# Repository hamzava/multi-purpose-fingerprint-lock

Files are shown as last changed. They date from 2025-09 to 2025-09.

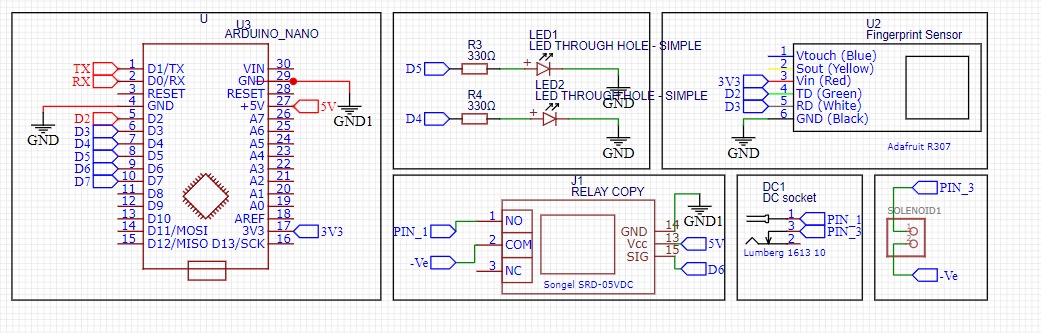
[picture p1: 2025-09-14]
Hardware/Circuit Schematic.jpeg

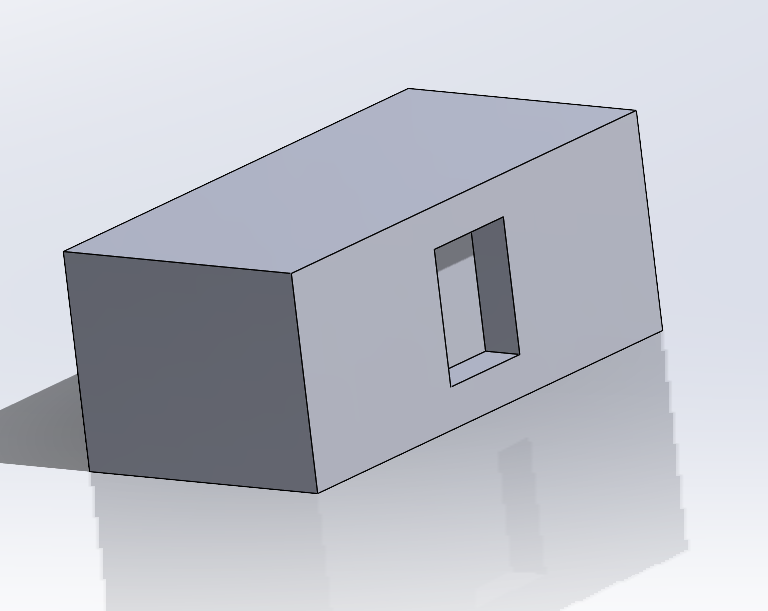
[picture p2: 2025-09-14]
Hardware/Case/image (2).png

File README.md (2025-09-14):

# Multi-Purpose Fingerprint Lock (Budget-Constrained Group Project)

Fingerprint Lock Prototype  

A prototype access-control system designed to provide **secure, low-cost, and user-friendly** locking solutions for doors, safes, and other objects requiring controlled access.  
This project was developed under strict **budget (£100)** and **time constraints**, highlighting practical engineering trade-offs and teamwork.

---

## 📖 Overview
Unauthorized access remains a persistent problem in both domestic and commercial settings.  
This project addresses the issue by designing a **fingerprint-based lock** using affordable components, while keeping the solution **multi-purpose and commercially feasible**.  

The prototype demonstrates how biometric authentication can be adapted into a cost-sensitive and scalable design.

---

## 🎯 Objectives
The project team set out to design a lock that is:
1. **Cheap** – affordable prototype made under £100.  
2. **Multi-purpose** – usable for doors, safes, and other lockable objects.  
3. **Commercially feasible** – potential to scale down costs via wholesale components.  
4. **Easy to use** – simple enrollment and unlocking process.  
5. **Secure** – reliable fingerprint authentication.  

---

## 🛠️ Development Process
1. **Hardware Integration** – Fingerprint sensor and solenoid wired to Arduino via a custom PCB.  
2. **Software Setup** – Libraries installed for fingerprint module and solenoid lock in Arduino IDE.  
3. **Programming** – Arduino coded to store fingerprints and trigger solenoid based on authorized access.  
4. **Testing & Debugging** – Prototype tested repeatedly to ensure consistency and security.  
5. **Enclosure Design** – Custom case built to house the PCB and lock mechanism, simulating a commercial product.  

---

## 📚 Research & Background
- **Theory**: Based on biometric authentication — unique physical characteristics (fingerprints) ensure reliable access control.  
- **Research**: Studied fingerprint recognition algorithms, available sensor types, and related security risks.  
- **Feasibility**: Compared with market products (~£90–£110 retail). Our prototype cost **£72.69 Total**, with scope for significant cost reduction in mass production (bulk components, no repeated R&D).  

---

## ⚙️ Hardware Components
- Arduino (ATmega-based)  
- Fingerprint Sensor Module  
- Solenoid Lock  
- Custom PCB  
- Power Supply  
- Enclosure (prototype casing)

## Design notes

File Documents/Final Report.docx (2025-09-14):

MULTI PURPOSE FINGERPRINT

LOCK

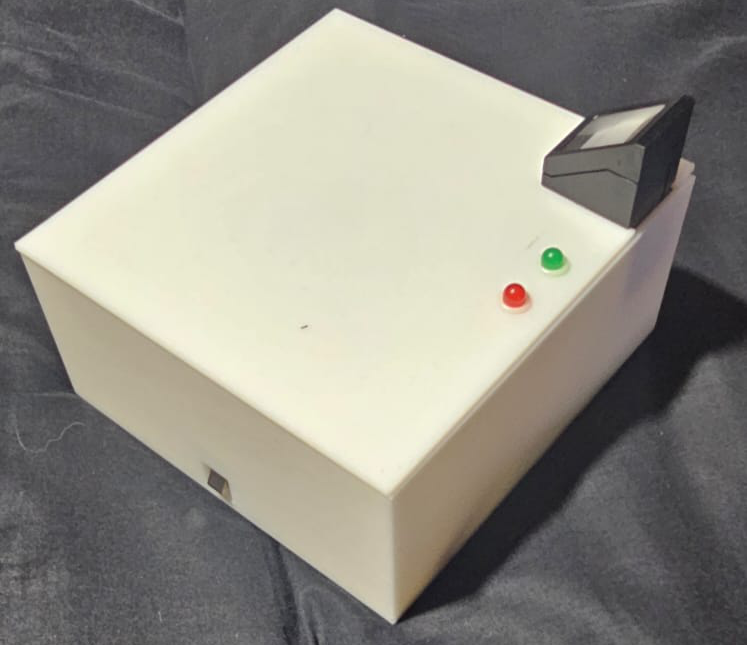
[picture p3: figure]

Group 1

Hamza Afzal, M.Ahsan Asif, Cameron Jones, Alex Ainsworth

# Introduction:

The purpose of this report is to document the development and evaluation of a multi-purpose fingerprint lock prototype, which was designed using an Arduino, fingerprint sensor, and a solenoid. The aim of the prototype is to provide a secure and convenient way to lock and unlock doors, safes, and other objects that require controlled access.

## Objectives/Problem:

The primary objective of the project was to design and develop a fingerprint lock that can be easily installed and configured to meet specific requirements. The project aimed to address the problem of unauthorized access to objects by providing a secure and reliable access control system.

Our goal was to design a fingerprint lock which is:

1. Cheap
2. Multi-purpose
3. Commercially feasible
4. Easy to use.
5. Secure

## Development:

The technique and procedure used for the development of the prototype involved the following steps:

1. Wiring the fingerprint sensor and solenoid to the Arduino board using PCB.
2. Installing the necessary libraries for the fingerprint sensor module and solenoid lock in the Arduino IDE software.
3. Programming the Arduino board to read fingerprints from the sensor and control the solenoid lock based on the authorized fingerprints.
4. Testing and debugging the prototype to ensure that it works as expected.
5. Creating a suitable case to hold the PCB and other components while making sure it is ready for commercial market.

# Background Research:

## Scope:

The scope of the project was to design and develop a prototype device that can be used for a variety of applications such as door locks, safe locks, and other objects that require controlled access. The prototype was designed to be easy to use, easy to install, and customizable to meet specific requirements.

## Theory:

The prototype was based on the theory of biometric authentication, which is a technology that uses unique physical or behavioural characteristics to verify the identity of an individual. The fingerprint sensor module used in the prototype is a type of biometric technology that scans and matches fingerprints to authorized users to provide secure access.

Research: Prior research on biometric authentication and fingerprint recognition was reviewed to determine the best practices for designing and developing a reliable and secure fingerprint lock prototype. The research focused on the different types of fingerprint sensors available, the algorithms used for fingerprint recognition, and the security risks associated with biometric authentication.

## Feasibility:

To justify the feasibility of the project, we will have to look at similar products. To do that we browsed Amazon and located products which are similar to ours and their application is similar to ours. Those products are available for sale, retail, ranging for 90-110 GBP. We made one single prototype under a budget of 100 GBP. If we are able to scale our product, we will have to buy components at wholesale rate which will reduce the cost. In addition to this, as R&D is not required for every product, that will also further reduce the cost.

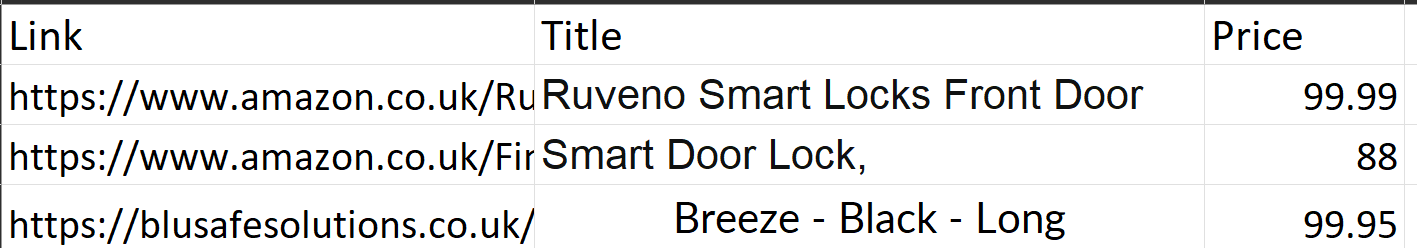
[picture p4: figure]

Price analysis

# Development & Test and Evaluation of Prototype:

Equipment, Apparatus and Technique & Procedure: The prototype was developed using the following equipment and apparatus:

1. Arduino Nano board

Worked as the core of the project. Holds the flash memory which include the code and fingerprints and co-ordinates between all the components because of the microprocessor it has.

2. Fingerprint sensor module

It is connected to the Arduino to scan the fingerprint and the Arduino processes it and stores it into it’s flash memory.

3. Solenoid lock

The solenoid lock is connect to the relay and Arduino. Relay acts as switch which receives the signal from Arduino. The signal determines that if the lock is supposed to be open or not. In either case Relay responds in such a way that solenoid behaves according to what we want.

4. USB cable

It was used to flash the code onto the Arduino.

5. Computer with Arduino IDE software

We wrote the code in Arduino IDE software so we could flash it later to the Arduino.

6. Solidworks
  a. Used to design the casing of the project and get it 3d printed.

# Design Phase

The casing was designed in Solidworks. Solidworks is a pretty good tool to design any 3d Object. Further it gives us option to save the file in such formats that we can get it 3d printed.

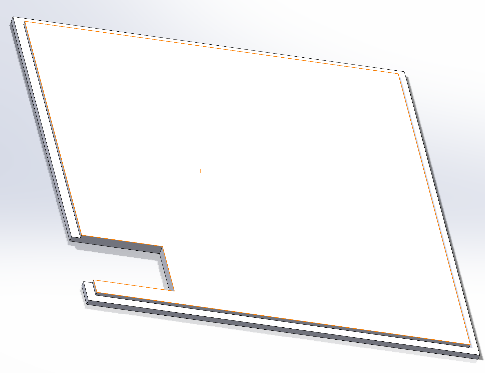
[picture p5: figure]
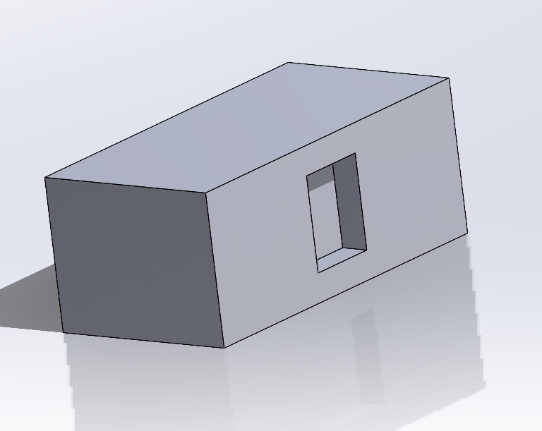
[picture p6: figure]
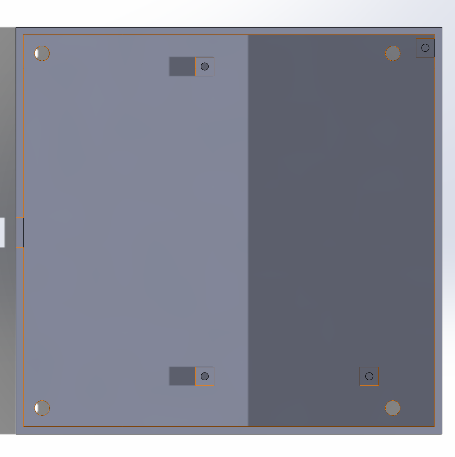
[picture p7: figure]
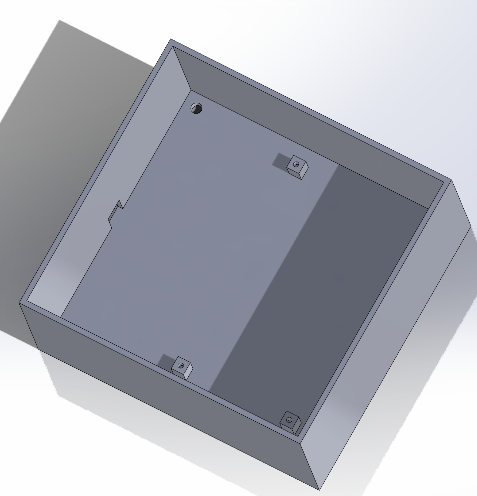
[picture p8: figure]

## Hardware:

Initially, we were able to demonstrate that our idea works. But the project was on breadboard. Usually that is the case with first prototypes, that they are on breadboard to show that it works because it is easier to change things as that is more of a test and improve approach.

We had ordered an external DC jack to power our project. So we would have different power source for solenoid as it draws 9V DC and a different power source for Arduino and other components. But we were able to figure out a way that we would only supply 9V to Arduino which in return would be able to power all the components.

Then when we had made sure that the project works, we changed the schematics. And we turned the schematics to a PCB. All our designing was done in EasyEDA. A technical part here was to make sure that the tracks which are going to be used for power are thicker than normal. Also we wanted to be on the safe side as well. The design of the PCB was as such that when we solder the components they are conveniently accessible. So placing the components at right place was really important. Furthermore, we had to design a lot of the components in EasyEDA as they weren’t available in the Library. Hence, this led to very accurate through holes in the PCB to solder components on.

When we tested the project, we were sure that we will only be using these parts. So we didn’t order any parts after that. This was also the plan because we discussed the components very thoroughly earlier in the R&D stage.

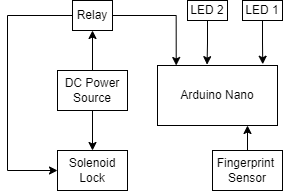
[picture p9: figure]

Hardware Block Diagram

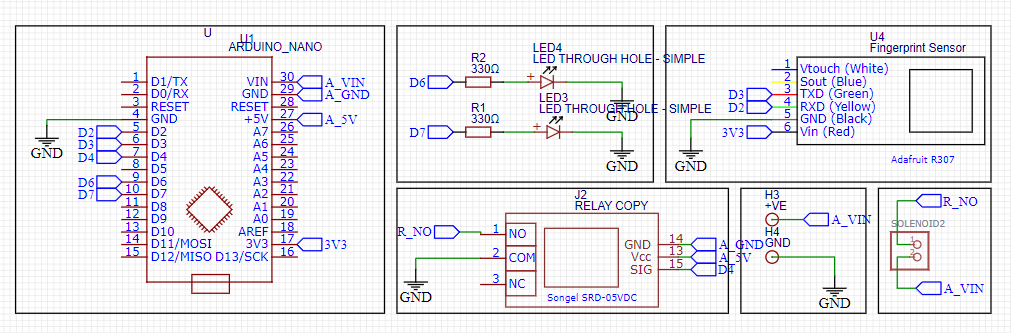
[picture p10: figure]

Circuit Schematic Diagram

After thinking about the hardware we discussed what are the appropriate components we needed for this project. So for that we did a lot of research as we had to make sure we are in our budget. After doing our research and finding appropriate components we ordered the following components.

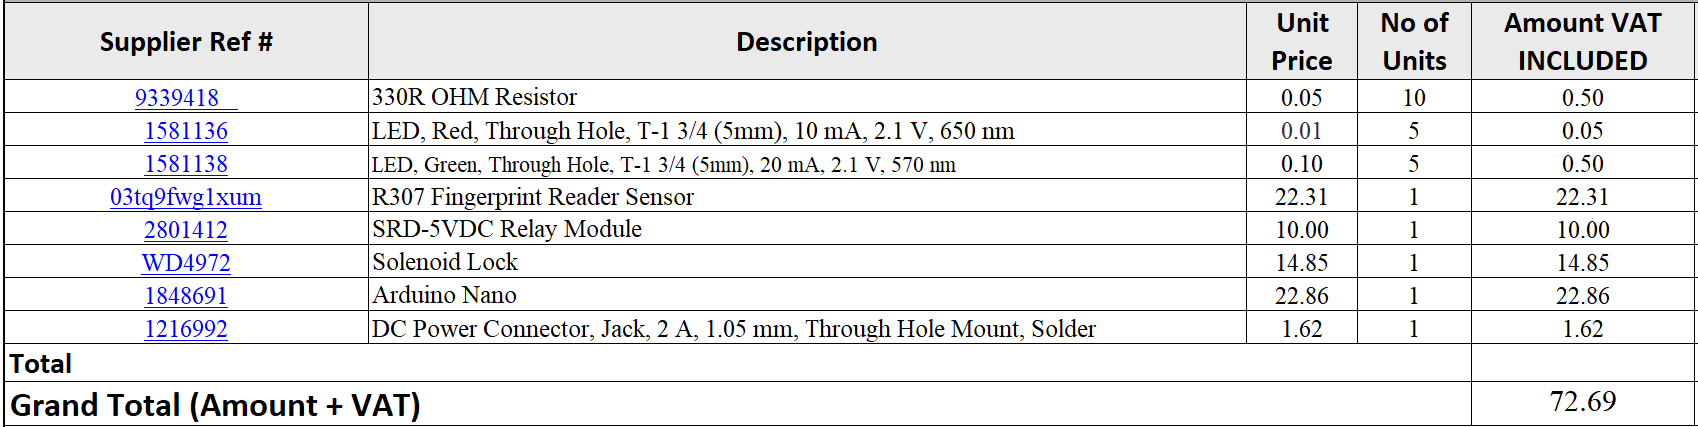
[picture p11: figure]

Order Form

## Software:

Our software’s algorithm is very straightforward. This helped us make the product work quicker. If we added more complexity, we were afraid that the response of the system might be slower. The current response time is about a second for registered fingerprints.

We have two parts of the code. First part is used to register the fingerprints. We can register up to 120 fingerprints. The code access’s the fingerprint module and it takes the picture of the fingerprint which is put onto it. The image is stored into the flash memory of the Arduino. This is the only part of the first code.

In the second code, the code access’s the fingerprint module. It takes the image of the fingerprint which on the module, it then compares that image with rest of the images stored in the memory. If the fingerprint is matched with any of the stored fingerprints. If it is the Arduino signals the Relay, which in return triggers the solenoid to an open state and changes the Led colour to Green. If the case is opposite, it does nothing, but keeps the Red Led on.

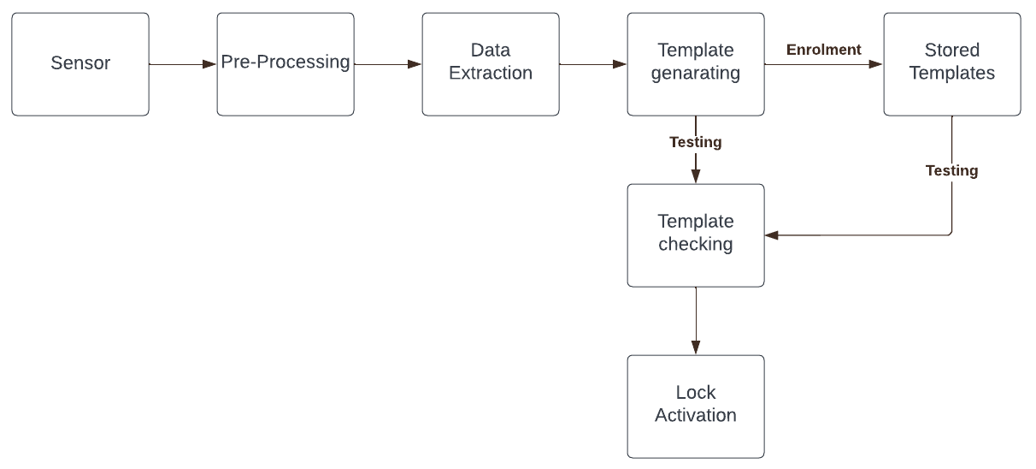
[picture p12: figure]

Combined Flowchart of the Software

# Testing:

The following procedure was used to test the prototype:

When the components came in, we got some faulty components as well. Which led us to check each component before we use that. For instance LED’s were supplied the required voltage individually through a power supply to make sure they are working and also making sure that they are not dim as we needed the perfect LED’s.

It is worth mentioning that we spent our budget not on 1 single quantity of each component, we ordered the parts in multiple quantities so that if anything goes wrong we are able to replace it except the Fingerprint sensor module and Arduino as they are expensive and for which we can get a work around. We got in multiple LED’s, Resistors and Solenoids according to the plan.

We used a multi meter which was provided by the university, to check voltage across the components and we made sure that they are only drawing enough current which is required to work. After that we made sure that all the components function properly. For instance, for fingerprint sensor we had to wait until the final code stage to check if it works. Although it did light up when the power was supplied but we still wanted to make sure that it read the fingerprint properly. Furthermore, we inspected the components visually, which came in help when the PCB’s arrived. There was a scratch on one of the PCB’s which would lead to a damaged track. So, we had to rule that PCB out and use another one as we had multiple PCB’s.

## Durability and Reliability Testing

For the durability testing of the product as we know most of the products were ordered and not made by ourselves, we were bound to follow the limitations set by the manufacturer. It is recommended that the product is used in an environment that has room temperature and moderately humid. But we worked out a range of from minus 5 degrees Celsius up to 45 degrees Celsius. This range also has been set up in such a way that the product will be safe to use in most of the case. This overall range has been worked out by considering the limits given to us by manufacturers. To prove that this range is perfectly fine we did put our product in the freezer for a - 5 degree test. And to test that it is fine to black in 45 degrees we used an oven. The test did go somewhat successful but at higher temperatures we know that usually the product do perform a little slower. But we think that if it is put into 45 degrees for a consistent amount of time the casing might get damaged. As the casing is 3D printed for prototyping purposes it might not cope with higher temperatures. The 3D printed cases depend on various factors. Like the amount of material we fill the object with. Hence that is what their prices and weight depends on. So we have to consider these factors when designing for commercial purposes.

(ada, n.d.) Fingerprint Module Temperature Rating

(Arduino, n.d.) Arduino Nano Temperature rating

(Farnell, n.d.) Solenoid Temperature Rating

Another important thing was the rejection rate and false acceptance rate of the fingerprint sensor.
Rejection rate is the rate with which the fingerprint sensor rejects a correct fingerprint. That usually is 1 in 100 if the fingerprint is maintained well like being keep free of dust and debris. This was verified by doing the experiment practically. And it was successful and upto the mark.

False acceptance rate is when fingerprint opens the lock with unauthorized fingerprint or it matches X’s fingerprint with Y’s. That ratio is 0.001 in 100 which is given by the manufacturer. As far as we used the fingerprint we never came across such a scenario while we had this in mind.

(ada, n.d.) Fingerprint Module FAR

In the URS we were specified that the battery time should be at least 12 hours. But currently we are managing to get around 4 hours. Currently, we use a 9v non rechargeable battery. We haven’t connect it directly to the PCB so if the user want’s they can attach a rechargeable one to the connector.

## Safety Testing

Our product is a product which uses electricity. Hence the only harm could be user being exposed to electricity and the hazards which are driven by electricity e.g fire. We designed the product so that all the wires are contained inside the case further more there are no wires outside the case. We also checked for any short circuits in the PCB so that there is not fire in case of a short circuit. We made sure that all the connections do have enough solder and they are soldered properly in addition to this we made sure none of the solder is colliding with other soldered wire. We also had to make sure that none of the tracks are burnt while soldering or they are not damaged as a result of manufacturing fault because of which could also cause sparks later on subsequently leading to a fire.

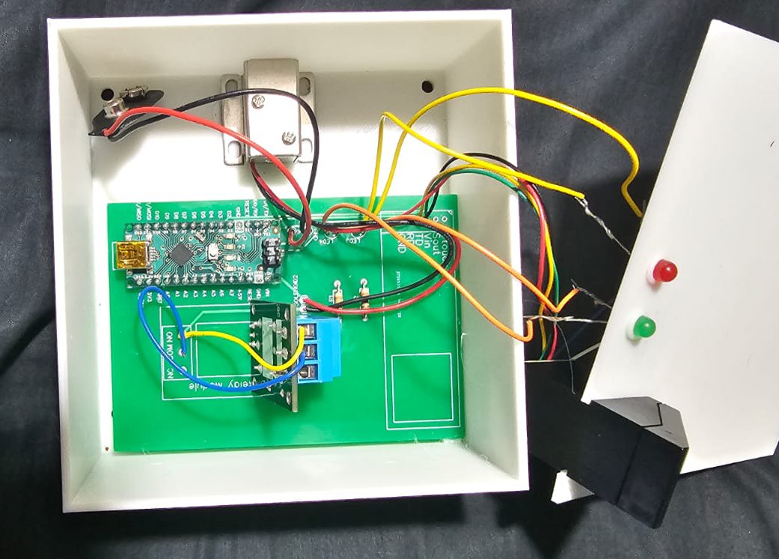
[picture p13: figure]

## User Testing.

Our product is designed completely from a consumer perspective. We were very conscious about the placement of components. Furthermore, we checked different position for fingerprint sensor, solenoid as well as LED to get the best possible position. This was a driving factor in the designing of the PCB as well as the 3D printed case. So the consumer of the product will be able to scan their fingerprint very easily as we have tucked the fingerprint module into the 3D case and made sure that it pops out. The reason that we wanted it to pop out was that the user should be able to scan their fingerprint properly. The current position of the fingerprint module made a 180 degree angle with the thumb or the finger of the user. And that was the best position determined after experimenting with the fingerprint module. In addition to this this was the position which gave us the best response from the system as we wanted the system to be quick enough to respond. If we scan the fingerprint in different position there was a high chance that the fingerprint won't be read properly.

Furthermore, the LED’s were put besides the fingerprint module because most of the times the user would be looking at the fingerprint sensor while scanning their finger or thumb. so while the user is looking at the fingerprint sensor when the fingerprint is scanned it would be shown on the green LED and it would give the user instant information that the lock is now open. So we had to also consider the psychology of the user. Another factor into designing our product was choosing the colour white. As we know that white colour absorbs less light hence it doesn't get heated that quickly. This was a drive from our side to make sure that we could be able to maintain the temperature of a running product as low as possible.

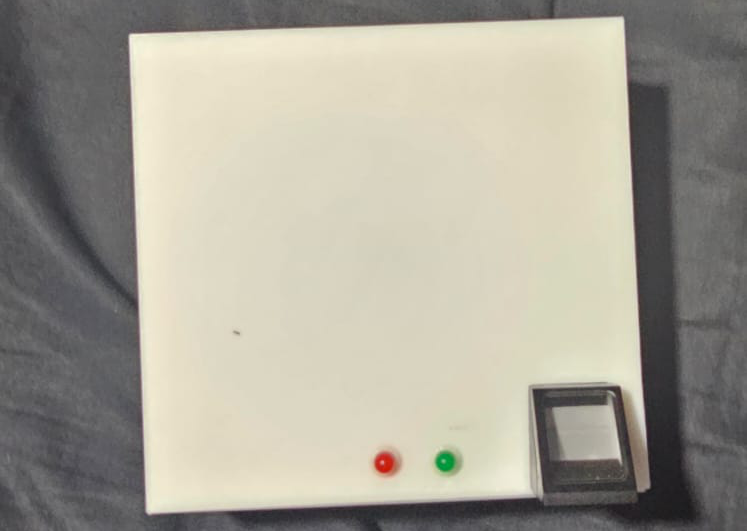
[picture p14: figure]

This testing was done by design and test approach because we wanted to initially design and think what we could improve over by testing the final model.

# Conclusion:

We were able to achieve the following outcomes from the project as in alignment with our interim report:

The prototype was successfully developed and tested, and the following results were obtained:

The fingerprint sensor module was able to accurately read and match fingerprints to authorized users.

The solenoid lock was able to lock and unlock object based on the authorized fingerprints.

The prototype was able to store multiple fingerprints and provide access to authorized users quickly and reliably.

Based on the results obtained, it can be concluded that the prototype is a reliable and secure way to control access to objects

## Reflection:

In our opinion our project could have been much better if the external factors didn’t matter as much.

First case is about the components. The deadline for to submit the order forms was before Christmas holidays which was met perfectly. But despite that we didn’t get our components on time as they were ordered after the Christmas holidays by the university. But we were able to produce a working prototype on a breadboard as it is much more feasible because of less Research and Development involved to develop a PCB. This was all done while meeting the deadline.

In another scenario for example, the PCB. We had guidelines to order the PCB through the university. But the PCB didn’t arrive until 2 days before we were supposed to present the final prototype. Although we had sent out the Gerber files just after we displayed our first prototype. Hence, we had very little time to implement the improvements we had thought about and ultimately the product was not somewhat we wanted. This all happened despite us meeting all our deadlines.

Furthermore we had lots of options which we could improve, for example one of the options was to decrease the on time for the red LED as it's usually on. We weren't able to do so because of the time constraints we had although this is a purely software based solution and this would also help us increase the battery time of the system. In addition to this one more change we wanted to do was that we wanted the system to be dependent on a lithium ion battery which are usually rechargeable. This would give the system the liberty of being remote which is specified in the URS but if we went for a DC Jack which means that the DC power is directly supplied from a outlet this would decrease the mobility of the system as they would need a socket to be beside or somewhere near the system.

If we were do add these things in the project I think the project would have been perfect considering the URS.

## Suggestion:

We met all our deadlines and completed the product we planned. But still in our opinion, it would have been much better that if we were authorized to order PCB’s and components. That would give us a much better grip on the project as we would be able to plan ahead of schedule.

# Manual:

1. Introduction

The multipurpose fingerprint sensor lock is a versatile security device that can be used to secure a wide range of items such as lockers, cabinets, and safes. It is equipped with advanced biometric technology that provides reliable and accurate identification of your fingerprints.

2. Installation

The installation process for the multipurpose fingerprint sensor lock will vary depending on the item you are securing. However, the basic steps are as follows:

Step 1: Prepare the item - Before installing the lock, ensure that the item is clean and free from any dust or debris. Remove any existing locks or hardware that may interfere with the installation.

Step 2: Install the lock - Align the lock with the hole on the item and insert the lock cylinder into the hole. Use the provided screws or adhesive tape to secure the lock in place.

Step 3: Install the battery - The lock is powered by 9V batteries. Open the compartment and insert the batteries according to the polarity markings.

Step 4: Register fingerprints - Follow the instructions provided to register your fingerprints. The lock can store up to 120 fingerprints.

3. Usage

Once the installation is complete and your fingerprints are registered, you can begin using the multipurpose fingerprint sensor lock. To unlock the item, simply place your finger on the sensor. The lock will quickly scan and verify your fingerprint before unlocking the item.

4. Maintenance

To ensure that the multipurpose fingerprint sensor lock continues to operate smoothly, it is important to perform regular maintenance. This includes:

- Keep the lock clean and free from dust and debris.
- Replace the batteries when they run out of power.
- Test the lock regularly to ensure that it is working correctly.
5. Troubleshooting

If you experience any issues with your multipurpose fingerprint sensor lock, please refer to the troubleshooting guide provided with the lock. Common issues include:

- The lock fails to recognize your fingerprint.
- The lock does not respond to input.
- The lock makes unusual sounds.

If you are unable to resolve the issue, please contact the manufacturer for assistance.

6. Conclusion

The multipurpose fingerprint sensor lock is a reliable and versatile security device that provides advanced protection for your valuable items. With proper installation, usage, and maintenance, you can enjoy many years of trouble-free operation.

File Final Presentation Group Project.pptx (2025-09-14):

## final GROUP PROJECT PRESENTATION

BY ahsan, hamza, alex and Cameroon

## introduction

- Introducing everyone's roles
- Why we chose a fingerprint lock?
- Improvements made to the model
- Conclusion

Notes: Demand in biometric authentication. AND ensuring security is met when using our fingerprint print lock

## Block diagrams

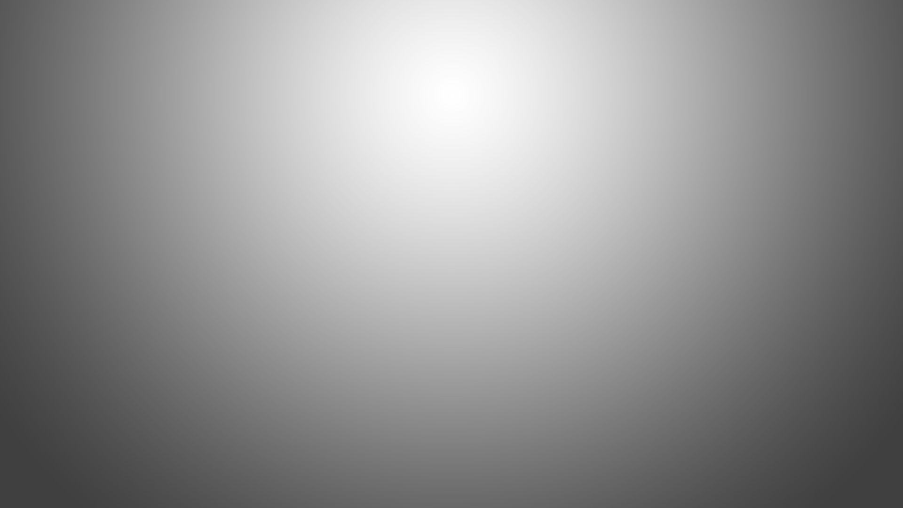
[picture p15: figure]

Hardware

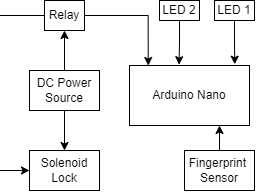
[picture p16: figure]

Software


## improvements

- CONVERTED BREADBOARD ONTO A PCB
- POWERED BY A 9V BATTERY
- CASE CREATED TO HOLD THE PROJECT
- COMMERICALLY SUITED

## Testing strategies

- Checked each component using a Multimeter
- Check voltage across each connection after soldering by using a Multimeter
- Used a power supply first then 9V battery

## CONCLUSION

- Gantt Chart targets met
- Completely working/assembled model
- Ready for launch

## Thank you for listening

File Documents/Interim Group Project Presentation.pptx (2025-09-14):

## Fingerprint lock with Arduino nano

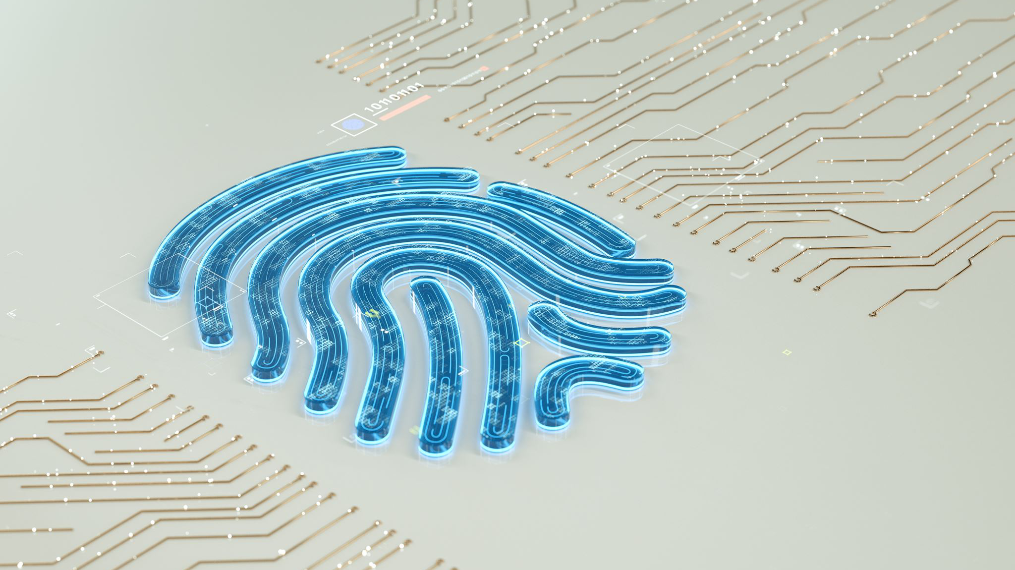
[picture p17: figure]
3D technology art

By Ahsan, Hamza, Alex and Cameron

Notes: Ahsan

Hello welcome all to our presentation. I’m Ahsan the group leader of this project and wanted to talk about our project which is about a Fingerprint lock with an Arduino Nano, In this presentation we will go over why we choose this project, the objectives and basic specifications of the product. The hardware and software details of the project and how we will test the project via the use of strategies. We will also include our Gantt Chart to show where we are in terms of the project and how much more we have left.

## Roles and Responsibilities

Ahsan : Group Leader : Overlooking group project and ensuring group sticks to tasks
Hamza : Secretary : Helps wherever possible and coordinating meetings
Alex : Hardware Engineer
Cameron : Software Engineer

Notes: First and foremost, I would like to introduce each of the members of the group and the responsibilities of each member, so everyone has an idea on what each member of the group is responsible for.

## Why a Fingerprint Lock?

## Basic System Objectives

1
The system must be able to store and manage multiple individual fingerprints.
2
The system must be able to accurately and reliably identify authorized individuals based on their fingerprints.
3
The system must be secure and resistant to tampering or unauthorized access.
4
The system must be able to grant or deny access to the secure area based on the verification results.

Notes: 2. So that there is no clash between the fingerprints

4. We two different coloured led for that.

## Basic Specification of the Fingerprint Scanner

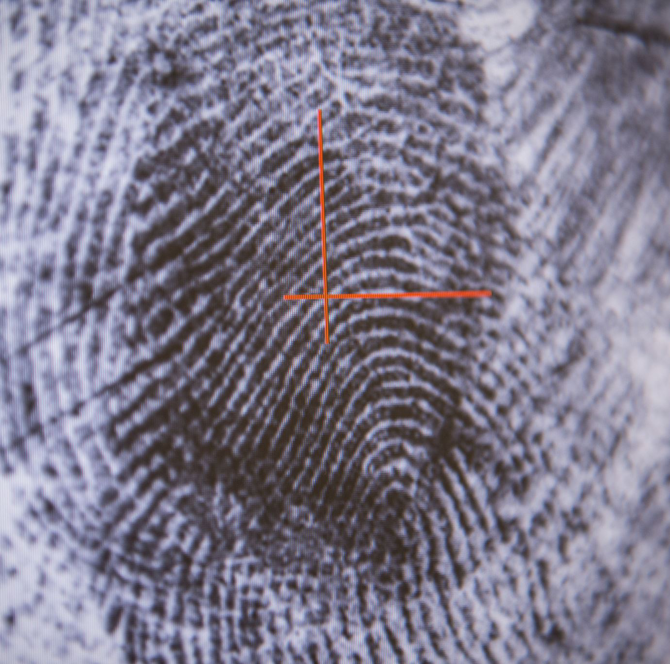
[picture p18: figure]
A fingerprint in black and white

- The system will use an optical fingerprint scanner.
- The system will use the flash memory microprocessor to store the fingerprint.
- The system will use the database of fingerprints in the flash memory to identify, and reject any false fingerprint.

## System Constraints & Assumptions

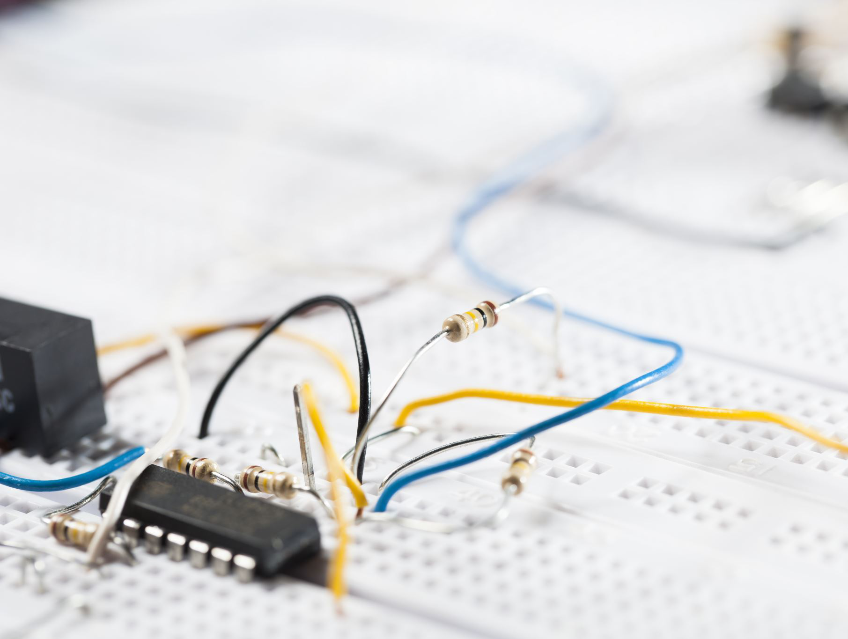
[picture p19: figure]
Electronics protoboard

- The system can be installed and used in a single location with a fixed secure area.
- The system will be connected to a power source.
- The system will be used by individuals with stable fingerprints.

## System Tolerances

- The system must have a high degree of accuracy, with a false acceptance rate (FAR) of no more than 0.001% and a false rejection rate (FRR) of no more than 1%.
- The system must be able to operate in a range of environmental conditions, including temperatures between -10°C and 50°C and relative humidity between 20% and 80%.
- The system must be able to operate continuously for at least 12 hours on a single battery charge.

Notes: alex

## Bill of Materials / Expenditure Description

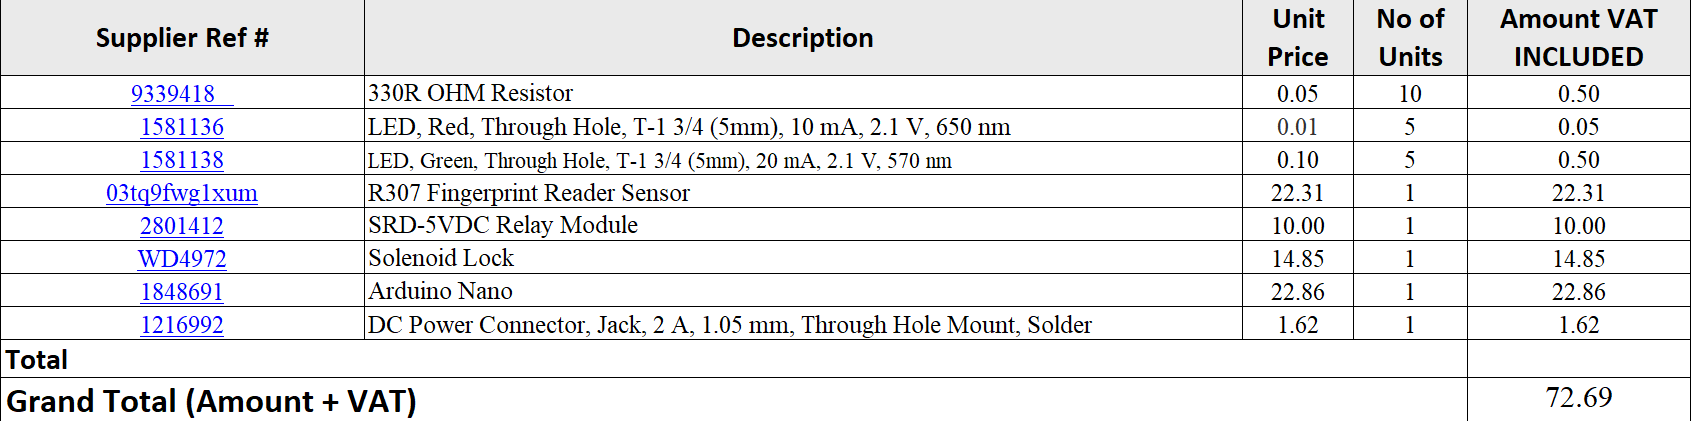
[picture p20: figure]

## Schematic Diagram & Block Diagram and : Hardware

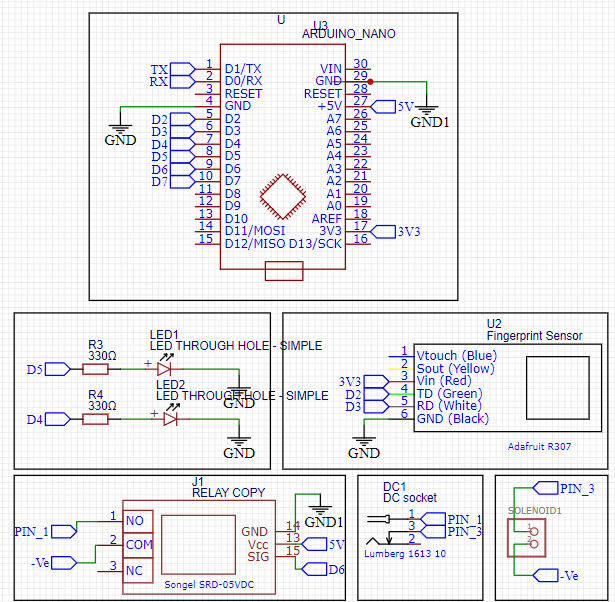
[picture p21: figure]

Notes: Hamza
Main Arduino
relay and solenoid connect to 12v dc because high powered Arduino supply’s 5v max


Fingerpritn sensor connected to Arduino signal to relay opens the solenoid

## Product Artifact and PCB

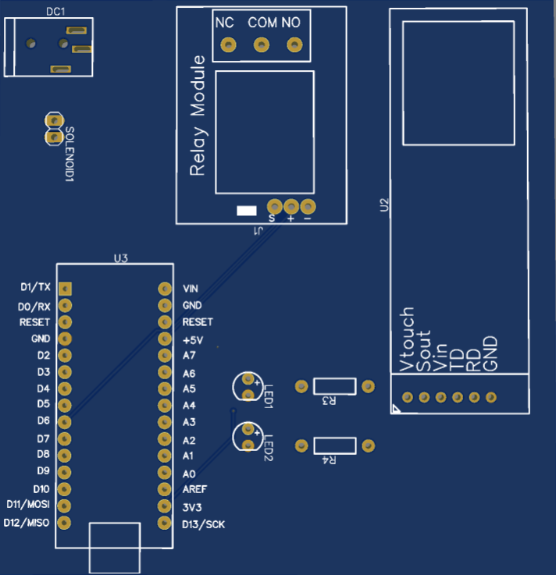
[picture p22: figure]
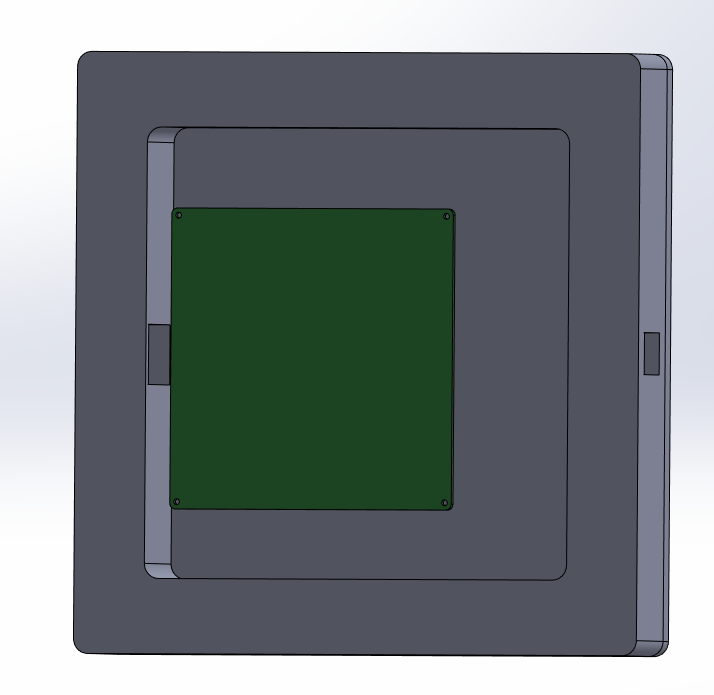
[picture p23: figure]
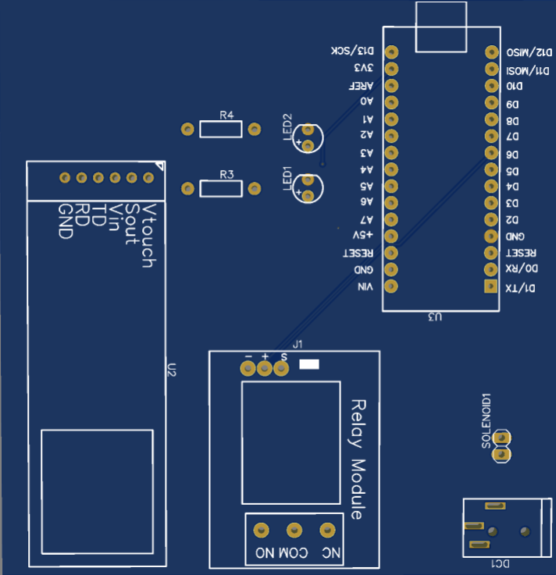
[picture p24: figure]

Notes: Hamza

## Testing Strategy

Functional Testing
Reliability Testing
Safety Testing
User Experience Testing

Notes: Hamza and Cameron

There are several testing strategies that you can use to test an electrical product, including the following:
Functional testing: This type of testing involves verifying that the product performs all of its intended functions correctly. This can include testing individual components, such as buttons, switches, and sensors, as well as testing the product as a whole to ensure that all of its functions work together properly.
Reliability testing: This type of testing is used to verify that the product is able to withstand the stresses of normal use and continue to function properly over time. This can include testing the product's durability, longevity, and resistance to damage or failure.
Safety testing: This type of testing is used to verify that the product is safe to use, both for the user and for any other individuals who may come into contact with it. This can include testing the product's electrical safety, such as ensuring that it complies with relevant safety standards and regulations.
User experience testing: This type of testing is used to evaluate how easy the product is to use and how well it meets the needs of the user. This can include testing the product's user interface, usability, and overall user experience.
These are just some examples of testing strategies that you can use to test an electrical product. The specific tests that you use will depend on the product and its intended use, and you may need to use a combination of different testing methods to thoroughly evaluate the product.

## Block Diagram and Specifications : Software


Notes: Cameron

## Risk Assessment

Risk No. | Description of the risk | Probability of the risk | Effect on the project | Contingencies/actions To mitigate the risk
1 | Burn from soldering iron. | If soldering iron is handled with care, probability of risk happening is low. | Can slow progress down as person will have to take care of injuries. | Wear heat proof gloves.
2 | Burn from hot solder splashing. | Fairly high probability of risk happening. | Takes up time but needing to take extra care is important for safety. | Wear long sleeves to protect skin and wear safety goggles to protect eyes.
3 | Short Circuit causing heat and possible fire. | High if components are damaged or not connected properly, very low if everything is connected as it should be. | Take extra time in building process as lots of attention will need to be put into the build to mitigate risk. | Test every component and connection/solder join, to make sure everything is in working order. This can be done easily by using a multimeter.
4. | Physical impact to fingers from building the product. | Fairly high if not being careful. Low if extra care is taken and you’re paying full attention to what you’re doing. | This will take extra time as it is most important to be safe when physically building the chassis of our product. | Keeping aware of surroundings and using building tools appropriately.
5. | Burn from welding | Heat and sparks could burn when welding, high probability without appropriate gear. | Will be strongest way of constructing our project but requires the correct knowledge on how to weld. | Wear correct protective gear and face shield, have the knowledge on welding techniques and methods.

## Gantt Chart

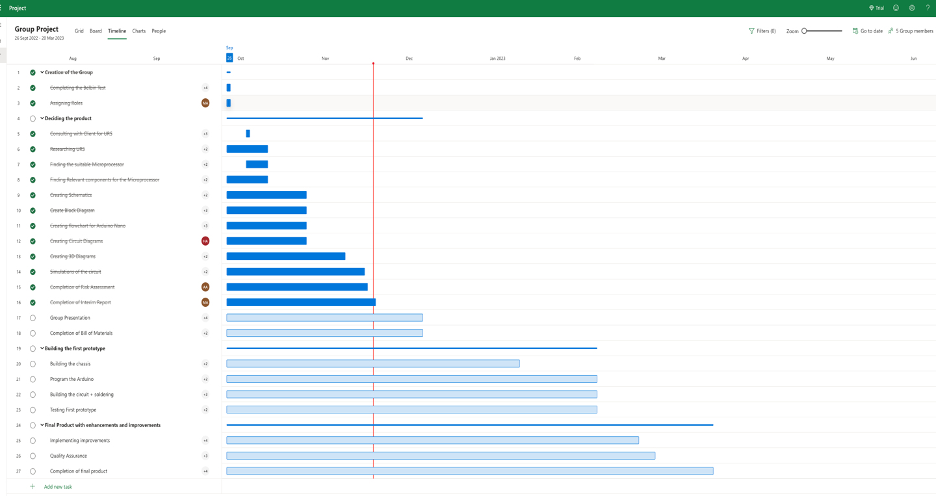
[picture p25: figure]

## Thank You for listening Any questions?

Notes: Ahsan

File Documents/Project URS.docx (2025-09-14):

#### 1. Introduction

This document describes the user requirements for a fingerprint lock system. The system will be used to control access to a secure area, allowing only authorized individuals to enter.

#### 2. General Requirements

- The system must be able to store and manage multiple individual fingerprints.
- The system must be able to accurately and reliably identify authorized individuals based on their fingerprints.
- The system must be easy to use and intuitive for authorized individuals to operate.
- The system must be secure and resistant to tampering or unauthorized access.

#### 3. Functional Requirements

- The system must be able to enroll new fingerprints and associate them with specific individuals.
- The system must be able to verify the identity of an individual based on their fingerprint.
- The system must be able to grant or deny access to the secure area based on the verification results.
- The system must be able to provide feedback to the user, such as indicating a successful verification or denying access.

#### 4. Non-Functional Requirements

- The system must have a high degree of accuracy, with a false acceptance rate (FAR) of no more than 0.001% and a false rejection rate (FRR) of no more than 1%.
- The system must be able to operate in a range of environmental conditions, including temperatures between -10°C and 40°C and relative humidity between 20% and 80%.
- The system must be able to operate continuously for at least 12 hours on a single battery charge.

#### 5. Constraints and Assumptions

- The system will be installed and used in a single location with a fixed secure area.
- The system will be connected to a power source.
- The system will be used by individuals with stable fingerprints.

6. User Interfaces

- The system will have a user interface consisting of a fingerprint scanner.
- The user interface will allow authorized individuals to enroll their fingerprints and access the secure area.
- The user interface will provide feedback to the user through LED’s, displaying a message indicating a successful verification or access denied.

#### 7. Technical Requirements

- The system will use a secure database to store enrolled fingerprints and associated information.

#### 8. Support and Maintenance

- The system will include a warranty period of at least 12 months.
- The system will be supported by the manufacturer with regular software updates and technical assistance.
- The system will be designed for easy maintenance and replacement of components, such as the fingerprint scanner or battery.

All rights reserved. Disclosure to third parties of this document or any part thereof, or the use of any information contained therein for purposes other than provided for by this document, is not permitted, except with prior and express written permission of Mobilefish.com. PROJECT-COMPANY-URD-00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

Multi Purpose Fingerprint Lock URS

Mobilefish.com document SDP-MF-URD-0001 javastreet 10 version 1.0 Zaandam date 3 Jul 2006 The Netherlands page i

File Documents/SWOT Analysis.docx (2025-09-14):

Strengths:

1. Accurate and reliable identification based on fingerprints
2. Secure and resistant to tampering
3. High degree of accuracy with low false acceptance and rejection rates
4. User-friendly and intuitive
5. Easy maintenance and component replacement

Weaknesses:

1. Limited to single location with fixed secure area
2. Dependent on power source
3. Limited to individuals with stable fingerprints

Opportunities:

1. Growing demand for secure access control systems
2. Potential for expanding to multiple locations
3. Integration with other security systems for enhanced security

Threats:

1. Competition from other security systems
2. Advancements in biometric technology may render fingerprint technology obsolete
3. Concerns about privacy and security of stored fingerprints.

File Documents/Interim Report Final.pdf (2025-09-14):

## Fingerprint Lock with Arduino Nano

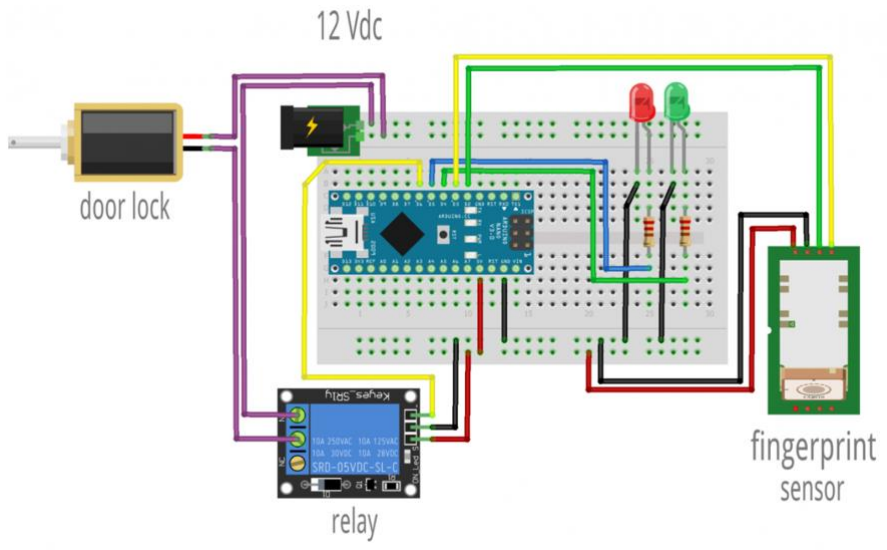
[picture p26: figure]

Authors: Muhammed Ahsan Asif, Hamza Afzal, Alexander Ainsworth and Cameron Jones

Supervisor: Ben Mehenni

Course: BEng Electrical and Electronic Engineering

Venue: University of South Wales Treforest Campus 2022-23

## Introduction

Our group project is to design and physically produce a robust fingerprint recognition lock with LED indicators that can be used to lock a safe. There are possibilities that our lock could extend into other prototypes and uses such as doors, suitcases, gates, cars, properties etc.

This project is being undertaken as fingerprint technology is now in widespread practice, which means we should learn about how the technology functions and try to understand how to build a product that can put it into practice. This project requires some coding as we are planning to use an Arduino Nano as our prototyping platform which contains an ATmega 328 microcontroller. The Arduino is to be powered via Micro USB. During the design of our project, we will learn how to code our lock so that it performs the specific tasks our product is required to do. This will also give an opportunity for our group to expand our understanding of how coding for the microcontroller works.

We plan to use a solenoid device as the foundation of our lock, specifically looking at the MP001162 Multicomp Pro, SOLENOID LOCK as our starting point. It is a small 12V, 9W solenoid and as we hopefully create more prototypes (for different purposes) we may change the solenoid as various products will require different specifications for the appropriate solenoid. The design will use LEDs to represent and indicate different states that the lock is in. Another option would be to use a small LCD screen, but this is impractical for a few reasons. LEDs will be cheaper, much more compact and space saving, more robust, much easier to code than an LCD screen and consume less power.

We will need to use a fingerprint sensor to receive information from somebody's fingerprint then transmit the information to the microcontroller. As we will have stored the fingerprint of the user, which is stored in the flash memory of the microcontroller, the microcontroller checks if the scanned fingerprint matches the fingerprint in the flash memory.

The fingerprint is going to be hardcoded in as this is the most secure way, we can do it due to weak security from the Arduino. However, we may use a different platform for subsequent prototypes such as Raspberry PI Pico which is more secure.

As we start to construct our project, we will need to make sure the dimensions of our project all fit together and are all compatible. It should fit in a safe chassis however if not our backup plan is to reengineer our locking system into a portable fingerprint lock or adapt it to different items such as a door, suitcase/briefcase lock.

Another point to add is we will need to solder our components onto a PCB containing the Arduino. We need to take care not to bridge any tracks, spill solder or break any components and therefore will require a steady hand.

## Summary/Background research of product

This section will talk about the background research which we have conducted for our idea and the justification of our chosen idea. Also, we will talk about the initial objections of our idea and how we dealt with these objections before finalising our idea.

Firstly, when deciding on our project, we thought of using the Renesas boards given to us in embedded for our project. This would be a viable option but due to our lack of knowledge of the architecture of the board and our programming skills for the board not being up to par, we decided not to use the Renesas board and decided on an Arduino Nano. An Arduino Nano was a viable option for us to use as it was inexpensive and most importantly easy to use. We could adapt pre-existing code which would help towards our project instead of completing learning how to program an embedded system which is hard for us to understand as of now or understanding an embedded systems architecture which we are unfamiliar with so we decided on an Arduino as we could implements more aspects into the Arduino as material is more available for it.

Now after deciding on using an Arduino Nano on our project, we needed to decide what we wanted to do with the Arduino. After brainstorming ideas, we decided on creating a safe lock with a fingerprint sensor. For us to work on this project, we needed to look at other lock systems with a fingerprint sensor to grasp the basics of how to conduct out project for our situation. This website demonstrates the use of a fingerprint scanner on a door lock system.¹ We can use the configurations of the fingerprint sensor from this project and use it in our project. After this discovery, we had the thought of using an RFID reader in our project. This website demonstrates the use of an RFID in an electric door lock.² The reason we didn’t decide to go forward with using an RFID due to the requirements of the user and to make the product as compact as possible. If we added the RFID, the size of the product which increase by at least 2 inches in dimensions.

Now, we have decided on the parts and have grasped the basic concepts of our project, now it’s time to find and research the schematics and circuit diagrams for our project.

1 Arduino Project Hub. (n.d.). DiY Fingerprint Door Lock System. [online] Available at:

https://create.arduino.cc/projecthub/diyprojectslab/diy-fingerprint-door-lock-system-98dcea.

2 Electric Door Lock With Fingerprint Scanner and RFID Reader. [online]. Available at:

https://www.instructables.com/Electric-Door-Lock-With-Fingerprint-Scanner-and-RF/. (https://create.arduino.cc/projecthub/diyprojectslab/diy-fingerprint-door-lock-system-98dcea)


3

Figure 1.1: Pin-out diagram of Arduino Nano

This image shows the pin-out diagram of the Arduino Nano takes from the Arduino website. This will allow us to understand how the Arduino works and tells us the significant of each pin and it’s use which will be useful for us.


4

Figure 1.2: Schematic of the Arduino Nano

3 Arduino® Nano. (n.d.). [online] Available at:

https://docs.arduino.cc/static/e7d6ca34b88350545d67282788df0956/A000005-datasheet.pdf

4 Figure 1.2, 1.3 and 1.4 : Arduino, n.d. Arduino Datasheet. [Online]
Avaliable at https://www.arduino.cc/en/uploads/Main/Arduino_Nano-Rev3.2-SCH.pdf


Figure 1.3: Schematic of the Microprocessor

Figure 1.4: Schematic of the USB Input

This is the schematic diagrams of the Arduino Nano, the microprocessor and the USB input taken from the Arduino website which is crucial for us as it allows us to render a 3d model of the Arduino Nano which can be rendered in Proteus.


5

Figure 1.5: Dimensions of the solenoid lock

6

Figure 1.6: Dimensions of the fingerprint sensor

5
Solenoid Lock Diagram Specifications Electrical Specifications. (n.d.). [online] Available at:

https://www.farnell.com/datasheets/2865763.pdf

6 Manual, U. (2011). R307 Fingerprint Module. [online] p.1. Available at:

https://www.openhacks.com/uploadsproductos/r307_fingerprint_module_user_manual.pdf

These are the dimensions of the solenoid lock and fingerprint sensor taken from the Farnell website. This diagram will allow us to redesign the solenoid lock and fingerprint scanner into proteus with the correct measurements and to create the 3D model of these two parts with precision.


6

Figure 1.7: Circuit diagram of Fingerprint sensor

This is the circuit diagram of fingerprint sensor taken from a GROW industries pdf which will allow us to understand the circuitry of the fingerprint sensor and the alignment of the pins which will be useful to us when constructing of the product.

6 Manual, U. (2011). R307 Fingerprint Module. [online] p.1. Available at: https://www.openhacks.com/uploadsproductos/r307_fingerprint_module_user_manual.pdf


7

Figure 1.8: Diagram of fingerprint scanner

This is a diagram which depicts how the fingerprint scanner works taken from the CircuitState website. This allows us to see what each of the scanner is and the purpose of each part of the scanner.

6

Figure 1.9: Schematic of fingerprint scanner

7
circuitstate.com. (n.d.). Interfacing R307 Optical Fingerprint Scanner with Arduino Boards for Biometric

Authentication - CIRCUITSTATE Electronics. [online] Available at: https://circuitstate.com/tutorials/interfacing-r307-

optical-fingerprint-scanner-with-arduino-boards-for-biometric-authentication/
6 Manual, U. (2011). R307 Fingerprint Module. [online] p.1. Available at: https://www.openhacks.com/uploadsproductos/r307_fingerprint_module_user_manual.pdf

This is the schematic of the fingerprint scanner taken from the GROW industries pdf. This will allow us to design of the fingerprint scanner in Proteus by helping us see where to wire each part with no complications. The schematic also allows us the render a 3D model of the sensor on Proteus so we can see a 3D model of the fingerprint scanner on Proteus.


Figure 2.10: Circuit Diagram of the planned product

This is a circuit diagram of our planned circuit which we design with a use of a breadboard. In our final project, instead of a breadboard, we will use a copper board and solder each of the components onto the board. This design gave us an insight on how the circuity would look like before constructing it in real life.

## Risk Assessment

- Generic risks

Generic Risks are risks that are generally there every day. Things like your surroundings and the scenario that you are in. For example, theft of materials, acts of God etc.

- Specific risks

Specific risks are risks that are special to the project of subject. This included things like making sure specific soldering techniques are being carried out. Soldering irons don’t generally have a place in everyday, urban environment.

Risk
No.

Description of
the risk

Probability of
the risk

Effect on the
project

Contingencies/actions
To mitigate the risk

### 1 Burn from

soldering iron.

If soldering iron is
handled with
care, probability
of risk happening
is low.

Can slow
progress down
as person will
have to take care
of injuries.

Wear heat proof gloves.

### 2 Burn from hot

solder splashing.

Fairly high
probability of risk
happening.

Takes up time
but needing to
take extra care is

Wear long sleeves to
protect skin and wear
safety goggles to
protect eyes.

| | | important for safety.
3 Short Circuit | causing heat and possible fire. | High if components are damaged or not connected properly, very low if everything is connected as it should be. | Take extra time in building process as lots of attention will need to be put into the build to mitigate risk. | Test every component and connection/solder join, to make sure everything is in working order. This can be done easily by using a multimeter.
4. Physical impact | to fingers from building the product. | Fairly high if not being careful. Low if extra care is taken and you’re paying full attention to what you’re doing. | This will take extra time as it is most important to be safe when physically building the chassis of our product. | Keeping aware of surroundings and using building tools appropriately.
5. Burn from | welding | Heat and sparks could burn when welding, high probability without appropriate gear. | Will be strongest way of constructing our project but requires the correct knowledge on how to weld. | Wear correct protective gear and face shield, have the knowledge on welding techniques and methods.

## WBS and Gantt Chart



These are the WBS of the tasks for the Gantt chart which was created on MS Project. Each task has a date and duration and has each of the members aligned to each task.


This is the Gantt chart of the overall project. The dark blue bars represent the completion of the tasks, and the light blue tasks shows the non-completion of tasks. The thin lines represent the duration of the overall task.

## Current state of project

As of the 18/11/2022, we have completed the Belbin test, assign roles, and have decided the project, completed the URS and have now completed the steps required for the Interim Report template. After submission, we will continue to update and use MS Project for tracking and start our next task which is preparation for the group presentation.

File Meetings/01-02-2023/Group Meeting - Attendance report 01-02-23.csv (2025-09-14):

1. Summary
Meeting title	Group Meeting
Attended participants	4
Start time	01/02/23, 22:50:48
End time	01/02/23, 23:12:59
Meeting duration	22m 11s
Average attendance time	21m 9s
2. Participants
Name	First join	Last leave	In-meeting duration	Email	Participant ID (UPN)	Role
Afzal H (FCES)	01/02/23, 22:50:52	01/02/23, 23:12:55	22m 2s	30052265@students.southwales.ac.uk	30052265@students.southwales.ac.uk	Organizer
Jones C (FCES)	01/02/23, 22:51:24	01/02/23, 23:12:59	21m 34s	30035734@students.southwales.ac.uk	30035734@students.southwales.ac.uk	Presenter
Ainsworth A (FCES)	01/02/23, 22:51:36	01/02/23, 23:12:56	21m 20s	30036209@students.southwales.ac.uk	30036209@students.southwales.ac.uk	Presenter
Asif M A (FCES)	01/02/23, 22:52:36	01/02/23, 23:12:16	19m 40s	30017471@students.southwales.ac.uk	30017471@students.southwales.ac.uk	Presenter
3. In-Meeting activities
Name	Join time	Leave time	Duration	Email	Role
Afzal H (FCES)	01/02/23, 22:50:52	01/02/23, 23:12:55	22m 2s	30052265@students.southwales.ac.uk	Organizer
Jones C (FCES)	01/02/23, 22:51:24	01/02/23, 23:12:59	21m 34s	30035734@students.southwales.ac.uk	Presenter
Ainsworth A (FCES)	01/02/23, 22:51:36	01/02/23, 23:12:56	21m 20s	30036209@students.southwales.ac.uk	Presenter
Asif M A (FCES)	01/02/23, 22:52:36	01/02/23, 23:12:16	19m 40s	30017471@students.southwales.ac.uk	Presenter

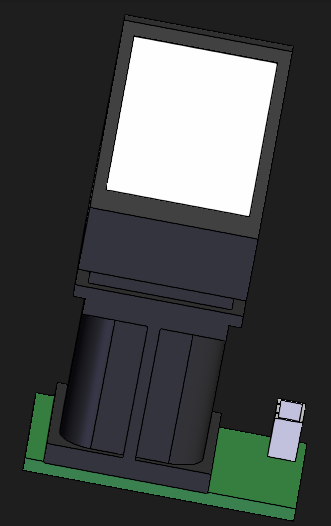
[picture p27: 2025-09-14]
Hardware/fingeprint.PNG

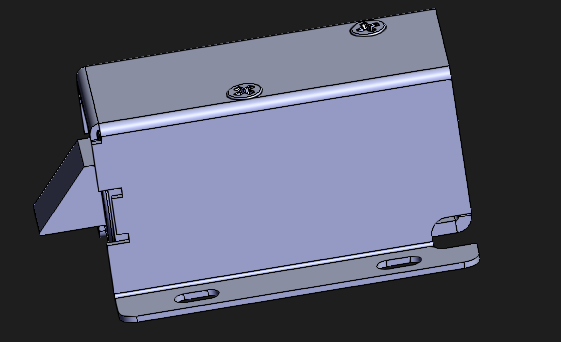
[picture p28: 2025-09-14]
Hardware/lock.PNG

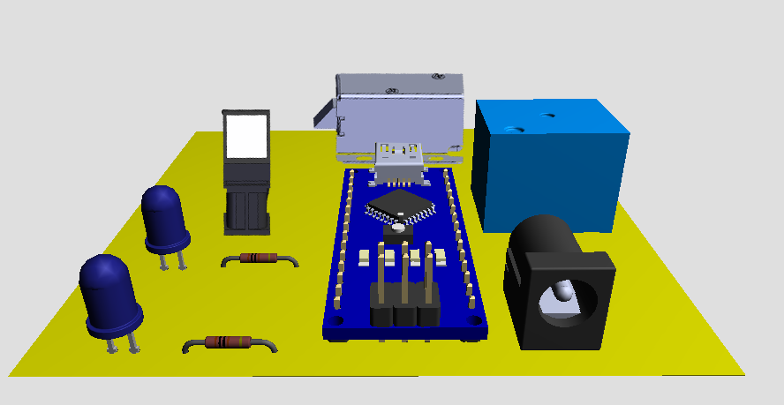
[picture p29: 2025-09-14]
Hardware/3d_Model.png

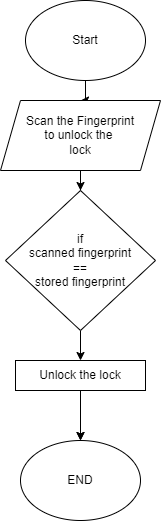
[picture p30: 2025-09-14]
Software/Flowchart 1.png

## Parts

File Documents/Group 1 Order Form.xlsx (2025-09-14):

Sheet: Sheet1
 |  |  |  |  | DFA ONLY
UNIVERSITY OF SOUTH WALES |  |  |  |  | Purchase method
FACULTY OF COMPUTING, ENGINEERING & SCIENCE |  |  |  |  | Date order raised
Please complete all the red mandatory fields, incomplete orders will not be processed. |  |  |  |  | Order Number
 |  |  |  |  | Nominal
EXPENDITURE REQUEST FORM
Section A
Date |  |  | Supplier Name and Address
Requested By
Credit Card / Order Request?
Budget Code
Department/Office
Authorisation (Print Name) Budget holder
 |  |  | Postcode:
Authorisation (Signature) |  |  | Tel No:
 |  |  | Fax No:
Goods or Services |  |  | If Equipment, please enter room where it is to be located :
Type of Goods / Services e.g. Software / Hardware |  |  | J407
Section B - Expenditure Description
Supplier Ref # | Description |  |  | Unit Price | No of Units | Amount VAT INCLUDED
9339418 (https://uk.farnell.com/multicomp/mcf-0-25w-330r/res-330r-5-250mw-axial-carbon/dp/9339418) | 330R OHM Resistor |  |  | 0.05 | 10 | 0.50
1581136 (https://uk.farnell.com/multicomp-pro/mcl053pd/led-5mm-36-hi-red/dp/1581136?MER=TARG-MER-PDP-RECO-STM7193) | LED, Red, Through Hole, T-1 3/4 (5mm), 10 mA, 2.1 V, 650 nm |  |  | 0.01 | 5 | 0.05
1581138 (https://uk.farnell.com/multicomp/mcl053gd/led-5mm-36-green/dp/1581138?st=green%20led%20through%20hole%205mm) | LED, Green, Through Hole, T-1 3/4 (5mm), 20 mA, 2.1 V, 570 nm |  |  | 0.10 | 5 | 0.50
03tq9fwg1xum (https://www.amazon.co.uk/Optical-Fingerprint-Attendance-Deposit-Control/dp/B08J48XZX4?hvadid=501068133807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) | R307 Fingerprint Reader Sensor |  |  | 22.31 | 1 | 22.31
2801412 (https://uk.farnell.com/mcm/83-17990/5v-trigger-relay-module-for-arduinoraspberry/dp/2801412) | SRD-5VDC Relay Module |  |  | 10.00 | 1 | 10.00
WD4972 (https://www.amazon.co.uk/QWORK-Electric-Solenoid-Assembly-Electirc/dp/B093H6GD4V?hvadid=570437819890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) | Solenoid Lock |  |  | 14.85 | 1 | 14.85
1848691 (https://uk.farnell.com/arduino/a000005/arduino-nano-evaluation-board/dp/1848691) | Arduino Nano |  |  | 22.86 | 1 | 22.86
1216992 (https://uk.farnell.com/lumberg/1613-10/socket-low-voltage-1-05mm/dp/1216992?st=lumberg+1613+10) | DC Power Connector, Jack, 2 A, 1.05 mm, Through Hole Mount, Solder |  |  | 1.62 | 1 | 1.62
Total
Grand Total (Amount + VAT) |  |  |  |  |  | 72.69
Section C Vehicle Hire PLEASE REFUEL VEHICLE
Delivery Date & Time
Delivery Point
Collection Date & Time
Collection Point
Vehicle Type / Description
Name(s) of Driver(s)
Purpose of Hire
Other Details : D.O.B |  | Flight no. : | Contact No. |  |  | Other Info
Driving Licence No. |  | Start date: | End Date
Failure to Refuel Vehicle will result in additional Charges and possible removal of service
Section D Accommodation Requirements ( only to be completed if not included in Uniglobe / Portman quote)
Name of Hotel
Address of Hotel
Hotel Telephone No / Fax No.
Dates Required
Number of Rooms Required
Names of Personnel
Additional Info Web address / Ref
Please submit electronically via email to: AT Expenditure Requests (AT)

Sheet: Sheet2
Credit Card | Goods | Electronic
Purchase Order | Services | Email attached

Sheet: Sheet3
Component | Arduino Nano Pin | Connection
Fingerprint RX | 2 | RX on fingerprint sensor
Fingerprint TX | 3 | TX on fingerprint sensor
Password | Not a pin
Relay COM | 5V | 5V on Arduino Nano
Relay NO | Solenoid + | Positive terminal on solenoid
Relay IN | 4 | IN on relay
Solenoid - | GND | GND on Arduino Nano
LED1 anode (+) | 6 | 6 on Arduino Nano
LED1 cathode (-) | GND | GND on Arduino Nano
LED2 anode (+) | 7 | 7 on Arduino Nano
LED2 cathode (-) | GND | GND on Arduino Nano
Fingerprint GND | GND | GND on Arduino Nano
Relay GND | GND | GND on Arduino Nano
Solenoid GND | GND | GND on Arduino Nano
Fingerprint VCC | 5V | 5V on Arduino Nano

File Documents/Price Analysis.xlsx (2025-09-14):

Link | Title | Price
https://www.amazon.co.uk/Ruveno-Fingerprint-Keyless-Electronic-Biometric/dp/B0B9XQJ3NP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 | Ruveno Smart Locks Front Door | 99.99
https://www.amazon.co.uk/Fingerprint-Bluetooth-Control-Perfect-Apartment/dp/B09P4W8SRY | Smart Door Lock, | 88
https://blusafesolutions.co.uk/product/breeze-black-long/ | Breeze - Black - Long | 99.95

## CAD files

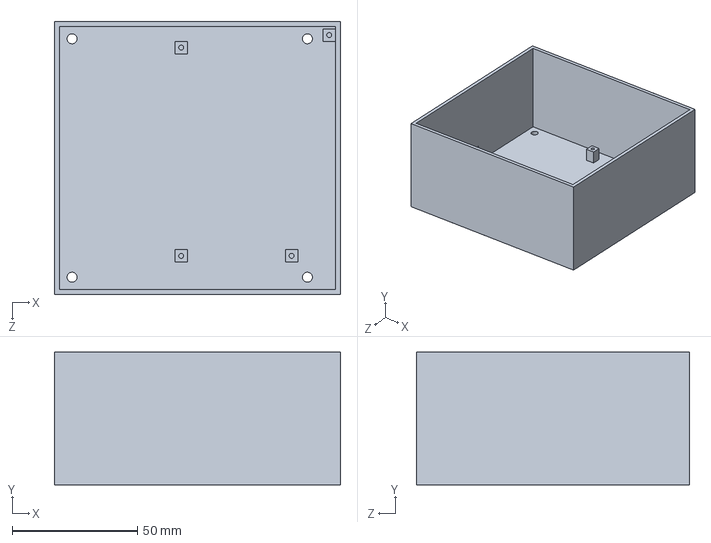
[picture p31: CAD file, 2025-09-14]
Hardware/Solidworks/box.SLDPRT
114.0 x 53.0 x 109.0 mm

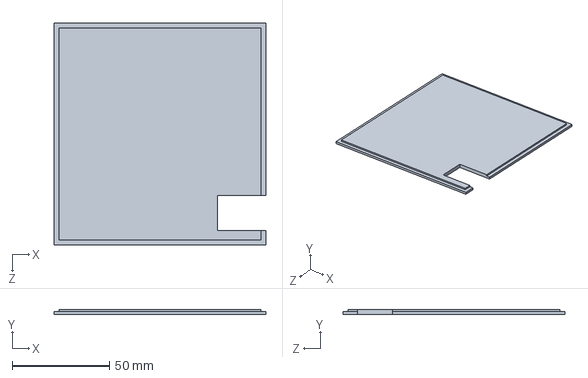
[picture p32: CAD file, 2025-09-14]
Hardware/Solidworks/lid.SLDPRT
109.0 x 2.50 x 114.0 mm

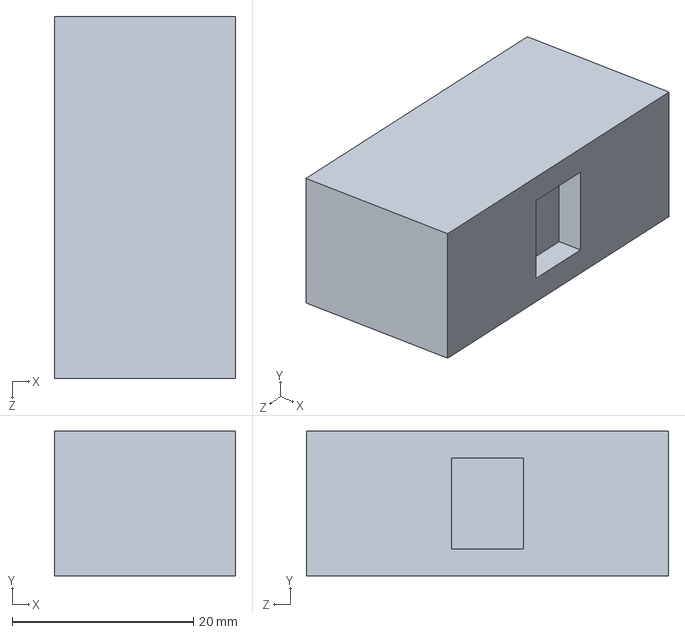
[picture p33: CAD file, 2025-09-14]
Hardware/Solidworks/lock.SLDPRT
20.0 x 16.0 x 40.0 mm

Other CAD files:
Hardware/Solidworks/box.STL
Hardware/Solidworks/lid.STL
Hardware/Solidworks/lock.STL

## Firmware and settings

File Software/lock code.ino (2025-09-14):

#include <Adafruit_Fingerprint.h>

SoftwareSerial mySerial(2, 3);
Adafruit_Fingerprint finger = Adafruit_Fingerprint(&mySerial);

#define RELAY_PIN       4
#define ACCESS_DELAY    3000 // Keep lock unlocked for 3 seconds 

int LED_GREEN = 6;
int LED_RED = 7;

void setup()
{
  //sets led pins as output
  pinMode(LED_GREEN, OUTPUT);
  pinMode(LED_RED, OUTPUT);
  // set the data rate for the sensor serial port
  finger.begin(57600);
  delay(5);
  if (finger.verifyPassword()) 
  {
  } 
  else 
  {
    while (1) { delay(1); }
  }
  
  pinMode(RELAY_PIN, OUTPUT);
  digitalWrite(RELAY_PIN, LOW);   //Switch off relay initially. Relay is LOW level triggered relay so we need to write HIGH.
}

void loop()
{
  if ( getFingerPrint() != -1)
  {
    //sets relay voltage to low to retract solinoid
    digitalWrite(RELAY_PIN, HIGH);
    //Sets led to show if fingerprint matches
    digitalWrite(LED_RED, LOW);
    digitalWrite(LED_GREEN, HIGH);
    //delays the code to allow door to be opened
    delay(ACCESS_DELAY);
    //relocks the solinoid
    digitalWrite(RELAY_PIN, LOW); 
    //show door is locked
    digitalWrite(LED_RED, HIGH);
    digitalWrite(LED_GREEN, LOW);
  }  
  delay(50);            //Add some delay before next scan.
}

// returns -1 if failed, otherwise returns ID #
int getFingerPrint() 
{
  int p = finger.getImage();
  if (p != FINGERPRINT_OK)  return -1;

  p = finger.image2Tz();
  if (p != FINGERPRINT_OK)  return -1;

  p = finger.fingerFastSearch();
  if (p != FINGERPRINT_OK)  return -1;

  // found a match!
  return finger.fingerID;
}
